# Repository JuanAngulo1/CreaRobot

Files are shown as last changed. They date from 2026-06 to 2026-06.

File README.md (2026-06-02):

# Sesame Robot — Build Guide (Custom Variant)

> Basado en el proyecto original [dorianborian/sesame-robot](https://github.com/dorianborian/sesame-robot) con modificaciones propias: alimentación por batería LiPo 2S con regulador LM2596, PCB personalizada y soporte para pantalla OLED con JST.

---

## Tabla de contenido

1. [Visión general](#1-visión-general)
2. [BOM — Lista de materiales](#2-bom--lista-de-materiales)
3. [Impresión 3D](#3-impresión-3d)
4. [Fase 1 — Electrónica: soldadura de la PCB](#4-fase-1--electrónica-soldadura-de-la-pcb)
5. [Fase 2 — Sistema de alimentación](#5-fase-2--sistema-de-alimentación)
6. [Fase 3 — Ensamblaje mecánico](#6-fase-3--ensamblaje-mecánico)
7. [Fase 4 — Montaje de la electrónica en el cuerpo](#7-fase-4--montaje-de-la-electrónica-en-el-cuerpo)
8. [Fase 5 — Calibración de servos](#8-fase-5--calibración-de-servos)
9. [Fase 6 — Firmware](#9-fase-6--firmware)

---

## 1. Visión general

El robot es un cuadrúpedo miniatura con 8 servos (2 por pata), controlado por un ESP32-S2 Mini (Lolin). La variante descrita aquí usa:

- Batería LiPo 2S (2× celda 14500 en battery holder 2S) → regulador buck LM2596 → 5 V para toda la electrónica.
- PCB de distribución personalizada con conectores JST XH 2.54 mm.
- Pantalla OLED SSD1306 0.96″ conectada por JST de 4 pines.
- Switch de encendido integrado en el top cover.

---

## 2. BOM — Lista de materiales

### Electrónica

| Componente | Especificación | Cant. |
|---|---|---|
| Microcontrolador | Lolin ESP32-S2 Mini | 1 |
| Servos | Tower Pro MG90S (o equivalente micro servo) | 8 |
| Pantalla OLED | SSD1306 0.96″, I2C | 1 |
| Regulador buck | LM2596 (módulo ajustable) | 1 |
| Batería | LiPo 14500 3.7 V × 2 (en battery holder 2S) | 2 |
| Switch | Rocker switch, enclave, 2 pines | 1 |

### Conectores y pasivos (para la PCB)

| Componente | Especificación | Cant. |
|---|---|---|
| Regleta hembra 2.54 mm | Para montar el ESP32-S2 Mini | 2 (según pinout) |
| Regleta macho 2.54 mm | Para señal de cada servo (S/VCC/GND por canal) | 8 × 3 pines |
| JST XH 2.54 mm 2 pines | Entrada de 5 V desde el buck | 1 |
| JST XH 2.54 mm 4 pines | Pantalla OLED (VCC, GND, SDA, SCL) | 1 |
| Cable 30 AWG | Señal | c/n |
| Cable 22 AWG | Potencia (VCC/GND servos y alimentación) | c/n |

### Hardware mecánico

| Componente | Especificación | Cant. |
|---|---|---|
| Tornillos autoroscantes | M2 × 5 mm | 10 |
| Tornillos métricos | M3 × 5 mm | 4 (regulador en techo) |
| Tuercas M3 | Para el regulador | 4 |

### Partes impresas en 3D

| Pieza | Cantidad |
|---|---|
| Marco interno (Internal Frame) | 1 |
| Top Cover | 1 |
| Bottom Cover | 1 |
| Joint L1, L2, L3, L4 | 1 c/u |
| Joint R1, R2, R3, R4 | 1 c/u |

---

## 3. Impresión 3D

Imprime todas las piezas antes de empezar el ensamblaje.

- **Material:** PLA (recomendado)
- **Relleno:** 30–40%
- **Capa:** 0.2 mm
- **Soportes:** Revisar el printing guide del repo original para orientaciones específicas del top cover

El set completo son **11 piezas impresas**: marco interno, top cover, bottom cover, y 8 joints (L1–L4, R1–R4).

![Componentes del robot]    
*Vista general de todos los componentes mecánicos e impresos*

---

## 4. Fase 1 — Electrónica: soldadura de la PCB

> Hazlo antes de tocar el ensamblaje mecánico. Con la PCB lista el cableado interno es mucho más limpio.

### 4.1 Montar el ESP32-S2 Mini

Solda dos **regletas hembra de 2.54 mm** en la PCB para que el ESP32-S2 Mini quede en zócalo (desmontable). El ESP32-S2 Mini requiere un reset manual para flashear (no tiene DTR/RTS automático), así que dejarlo desmontable facilita la vida.

### 4.2 Regletas para servos

Por cada uno de los 8 servos, solda una **regleta macho de 3 pines** (Señal / VCC / GND). Etiquétalas del 0 al 7 según el mapa de pines del firmware. Los servos L1–L4 y R1–R4 conectan aquí.

### 4.3 Conector de alimentación (entrada 5 V)

Solda un **JST XH 2.54 mm de 2 pines** para recibir los 5 V desde la salida del regulador LM2596. Esta es la única fuente de alimentación de toda la PCB (ESP32 + servos).

### 4.4 Conector de pantalla OLED

Solda un **JST XH 2.54 mm de 4 pines** con el siguiente orden:

```
Pin 1 → VCC (3.3 V o 5 V según la pantalla)
Pin 2 → GND
Pin 3 → SDA  (GPIO 33 en el S2 Mini por defecto)
Pin 4 → SCL  (GPIO 35 en el S2 Mini por defecto)
```

> Verificar el pinout exacto en el archivo de firmware antes de soldar.

### 4.5 Checklist de PCB

- [ ] ESP32-S2 Mini en zócalo, sin cortocircuitos visibles
- [ ] 8 regletas de servo soldadas y etiquetadas (0–7)
- [ ] JST 2 pines de alimentación
- [ ] JST 4 pines de OLED con orden VCC/GND/SDA/SCL correcto

---

## 5. Fase 2 — Sistema de alimentación

### 5.1 Batería

Usa **2 celdas 14500** (3.7 V cada una) en un **battery holder 2S**. Con ambas en serie obtienes ~7.4 V nominal (8.4 V cargadas). El holder va en la cavidad del Bottom Cover.

### 5.2 Regulador LM2596

El LM2596 convierte los 7.4–8.4 V de la batería a **5 V estables** para todo el sistema.

**Procedimiento de ajuste (trimear) antes de instalar:**

1. Conecta la batería (sin carga) al input del LM2596.
2. Con un multímetro en la salida, ajusta el **potenciómetro** del módulo hasta leer exactamente **5.0 V**.
3. Verifica con una carga leve (ej. una resistencia de 10 Ω) que la tensión se mantiene estable.

**Instalación:** El regulador se monta en el interior del top cover, pegado al techo, sujeto con **4 tornillos M3 × 5 mm** + tuercas. Deja espacio para que el potenciómetro quede accesible si necesitas reajustar.

### 5.3 Switch de encendido

El rocker switch se integra en el top cover. Se corta el positivo de la batería y se interrumpe con el switch — cuando está en OFF desconecta completamente el pack.

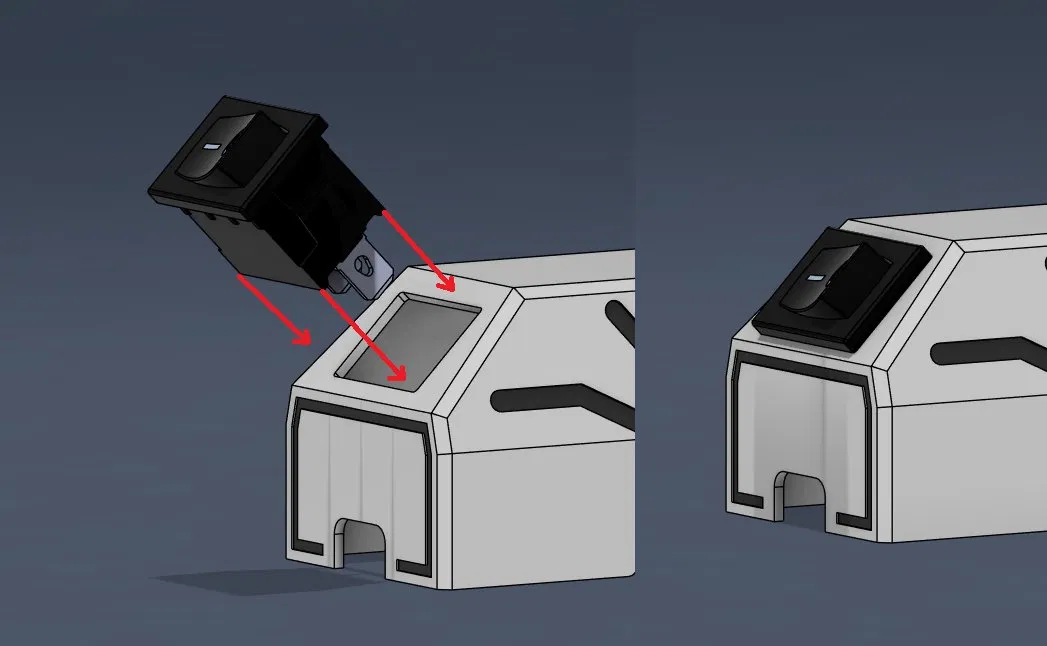
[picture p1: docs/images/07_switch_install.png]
Montaje del switch

*El switch encaja en la ranura del top cover presionando desde arriba*

---

## 6. Fase 3 — Ensamblaje mecánico

### 6.1 Montaje de servos en joints L3, L4, R3, R4 (patas traseras/delanteras, motor lateral)

Cada joint lateral (L3/R3 = muslo, L4/R4 = tibia) recibe un servo con el **engranaje apuntando hacia arriba** desde la perspectiva de la pata.

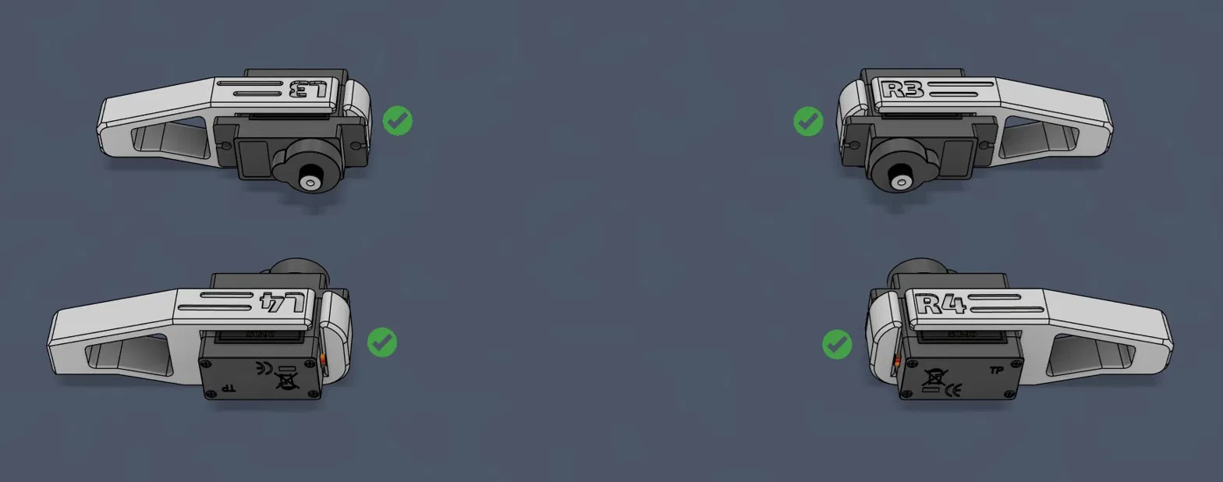
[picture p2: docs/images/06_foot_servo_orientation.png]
Orientación correcta L3/R3 y L4/R4

*Check verde = orientación correcta del servo en cada joint*

Fijación: **2× M2 × 5 mm autoroscantes** por servo (los orificios de montaje del servo encajan en el slot del joint).

### 6.2 Montaje de servos en joints L1, L2, R1, R2 (cadera)

Los joints de cadera son la articulación entre el cuerpo y la pata. Se montan en pares (L1+L2 lado izquierdo, R1+R2 lado derecho).

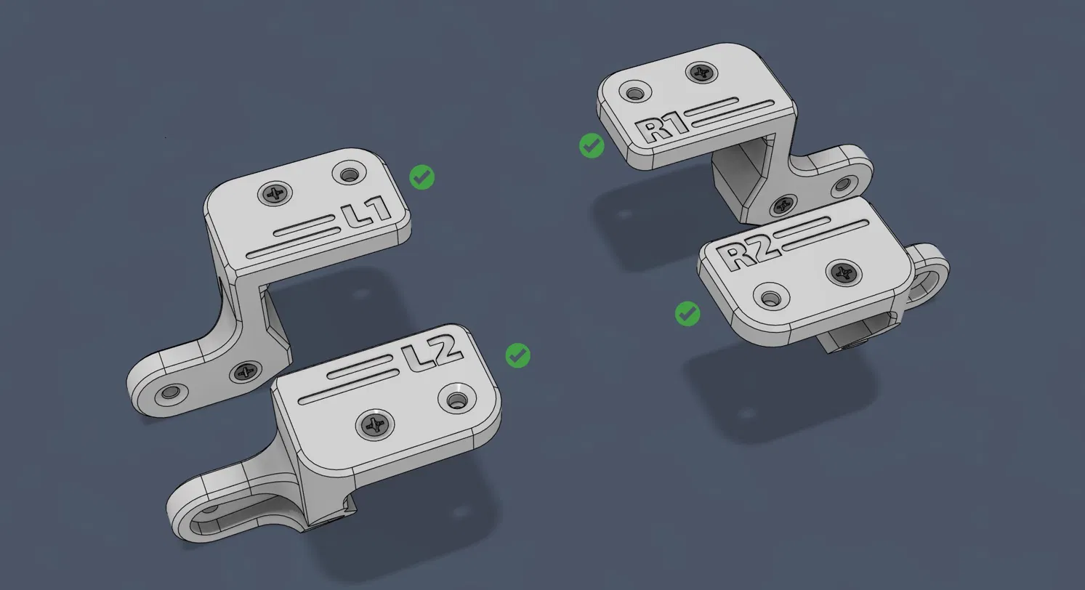
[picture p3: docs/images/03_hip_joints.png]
Joints de cadera L1/L2 y R1/R2

*Los cuatro joints de cadera, verificados con check verde*

> ⚠️ En este punto **NO montes todavía los servos** en los joints de cadera. Primero van los joints al frame, después los servos. Ver imagen de referencia:

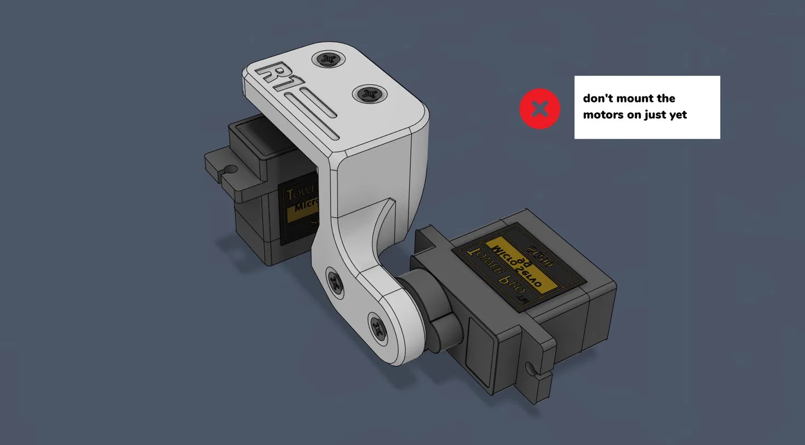
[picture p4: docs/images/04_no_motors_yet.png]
No montar servos todavía


### 6.3 Montaje en el marco interno

Los servos de cadera (motores 1–4, que corresponden a L1/L2/R1/R2) se insertan en el internal frame desde abajo. El servo desliza hacia arriba dentro de su slot, con las pestañas del servo encajando en las guías del frame.

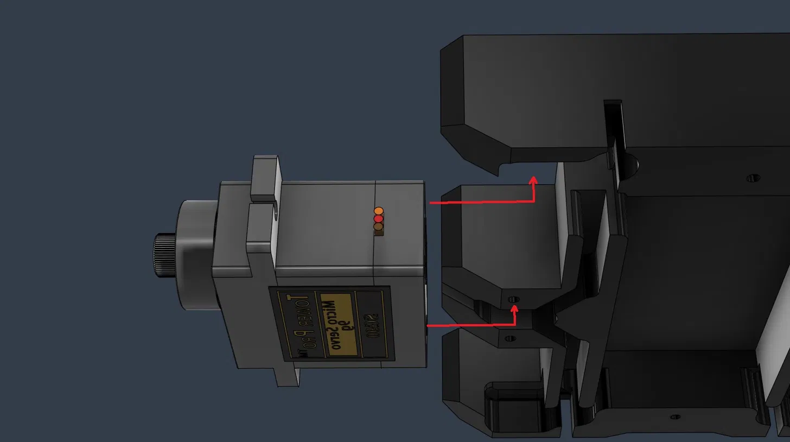
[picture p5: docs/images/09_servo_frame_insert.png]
Inserción del servo en el frame


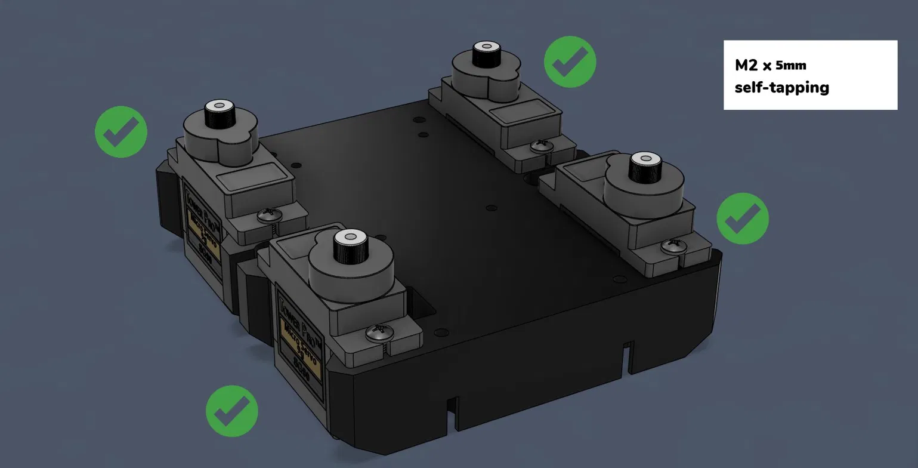
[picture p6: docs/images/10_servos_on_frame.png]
Los 4 servos montados en el frame

*4 servos fijados al frame con M2 × 5 mm self-tapping, check verde en cada esquina*

### 6.4 Verificación de orientación antes de continuar

Con los joints y el frame armados, revisa que la geometría de patas corresponda al diagrama de ángulos. **Todos los servos deben estar a 90° para el ensamblaje inicial** (posición neutra):

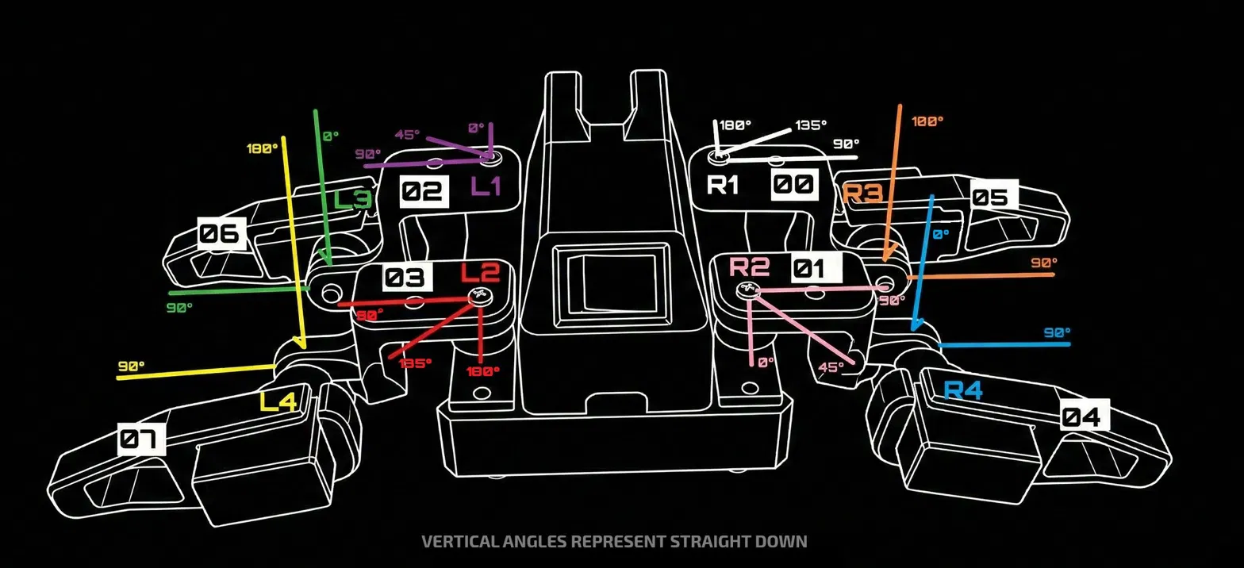
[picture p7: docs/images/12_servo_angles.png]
Diagrama de ángulos

*Mapa de ángulos objetivo por servo. "Vertical angles represent straight down"*

---

## 7. Fase 4 — Montaje de la electrónica en el cuerpo

### 7.1 PCB en el internal frame

La PCB de distribución va en el internal frame. Alinea los orificios de montaje y fija con tornillos M2.

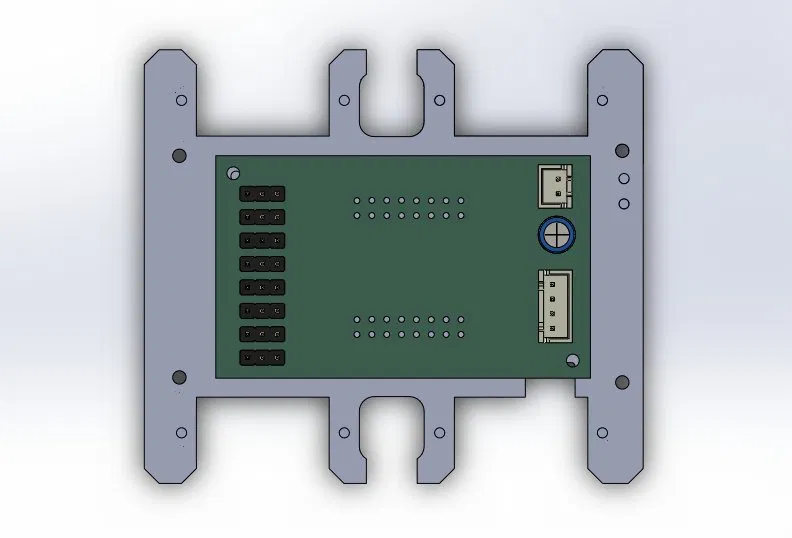
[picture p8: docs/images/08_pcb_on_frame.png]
PCB en el frame


### 7.2 Regulador en el top cover

El LM2596 va en el interior del top cover, pegado al techo. Sujétalo con los **4 M3 × 5 mm** mencionados en la Fase 2.

### 7.3 Pantalla OLED

La pantalla tiene un soporte impreso que la fija en la ranura frontal del top cover. Conecta el cable JST de 4 pines que va de la pantalla a la PCB.

### 7.4 Batería en el bottom cover

El battery holder 2S va en la cavidad del bottom cover. El cable positivo pasa por el switch antes de llegar al input del LM2596.

---

## 8. Fase 5 — Calibración de servos

Antes de poner los brazos de servo (servo horns) en su posición definitiva, todos los servos deben estar en **90°**.

1. Flashea `sesame-motor-tester.ino` (debugging firmware) al ESP32-S2 Mini via Arduino IDE.
2. Abre el Serial Monitor a 115200 baud.
3. Sigue el menú para mover cada servo individualmente a 90°.
4. Anota el offset de cada canal si el servo no queda perfectamente centrado.
5. Fija el servo horn con los servos ya en 90° antes de cerrar las articulaciones.

> Los offsets se ajustan en los parámetros de configuración del firmware principal.

---

## 9. Fase 6 — Firmware

### 9.1 Requisitos

- Arduino IDE con soporte para ESP32 (board manager: `https://raw.githubusercontent.com/espressif/arduino-esp32/gh-pages/package_esp32_index.json`)
- Board seleccionada: **LOLIN S2 Mini**

### 9.2 Flash del firmware principal

```bash
# Clonar el repo
git clone https://github.com/dorianborian/sesame-robot.git
cd sesame-robot/firmware
```

Abre `sesame-firmware-main.ino` en Arduino IDE y carga al ESP32-S2 Mini.

> ⚠️ El S2 Mini **no tiene DTR/RTS automático**. Para entrar en modo bootloader: mantén presionado **BOOT**, presiona y suelta **RST**, luego suelta **BOOT**. Después de flashear, presiona RST una vez para arrancar.

### 9.3 Control

Una vez encendido, el ESP32 levanta un **Access Point WiFi**. Conéctate desde tu teléfono a la red del robot y accede a la IP del AP (normalmente `192.168.4.1`) para ver el control web.

## Checklist final de ensamblaje

- [ ] PCB soldada y revisada sin cortocircuitos
- [ ] Regulador LM2596 trimeado a 5.0 V
- [ ] Switch probado (corta el positivo correctamente)
- [ ] Todos los servos centrados a 90° con `sesame-motor-tester`
- [ ] Joints y servos orientados según el diagrama de ángulos
- [ ] OLED conectada y mostrando algo al encender
- [ ] Firmware principal cargado, WiFi AP activo
- [ ] Batería colocada en el bottom cover, robot cierra correctamente

---

*Basado en [dorianborian/sesame-robot](https://github.com/dorianborian/sesame-robot). Variante con LiPo 2S + LM2596 + PCB de distribución personalizada.*

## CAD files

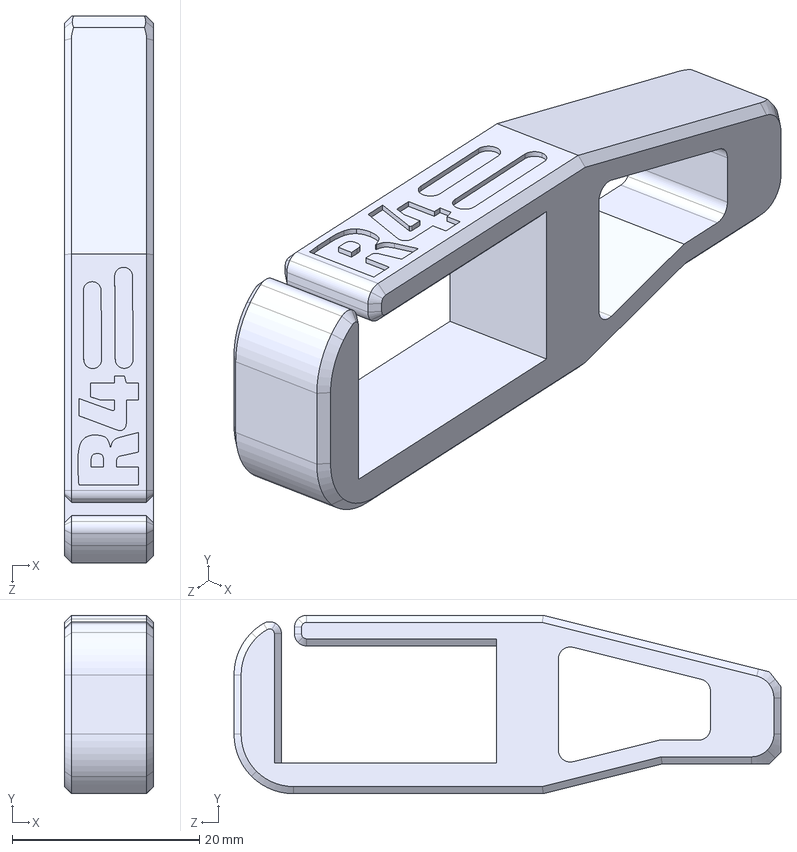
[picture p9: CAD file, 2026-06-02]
hardware/cad-printing/foot-joint-R4.step.STEP
9.53 x 19.1 x 58.4 mm

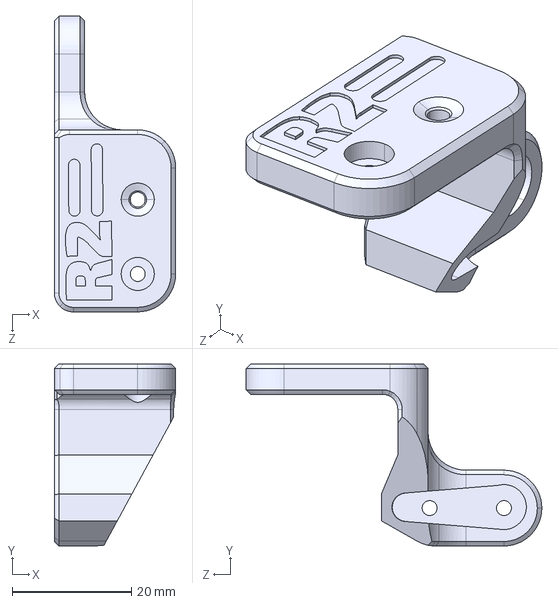
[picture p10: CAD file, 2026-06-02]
hardware/cad-printing/femurjoint-R2.STEP
20.3 x 30.5 x 49.5 mm

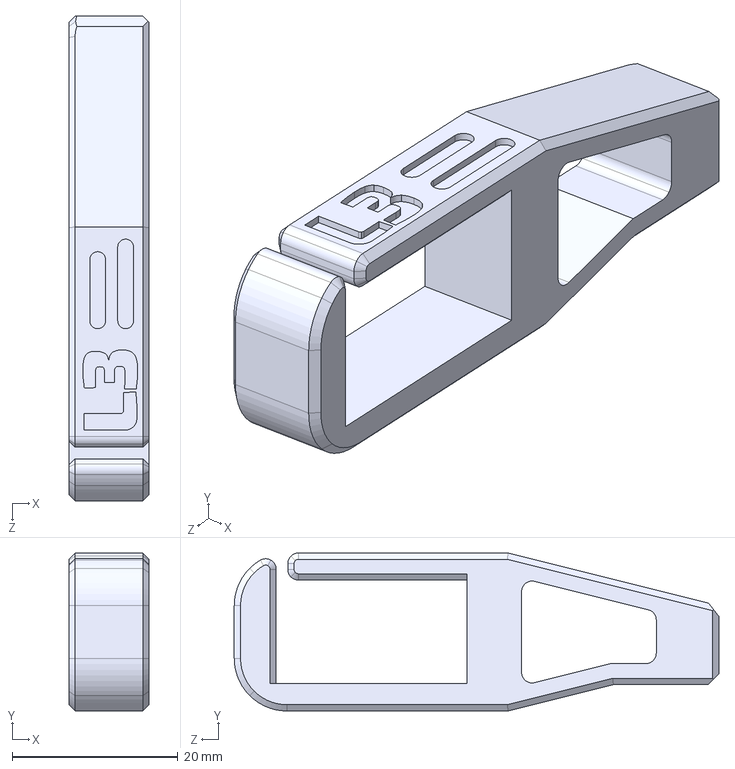
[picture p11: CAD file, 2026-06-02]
hardware/cad-printing/foot-joint-L3.step.STEP
9.70 x 19.1 x 58.4 mm

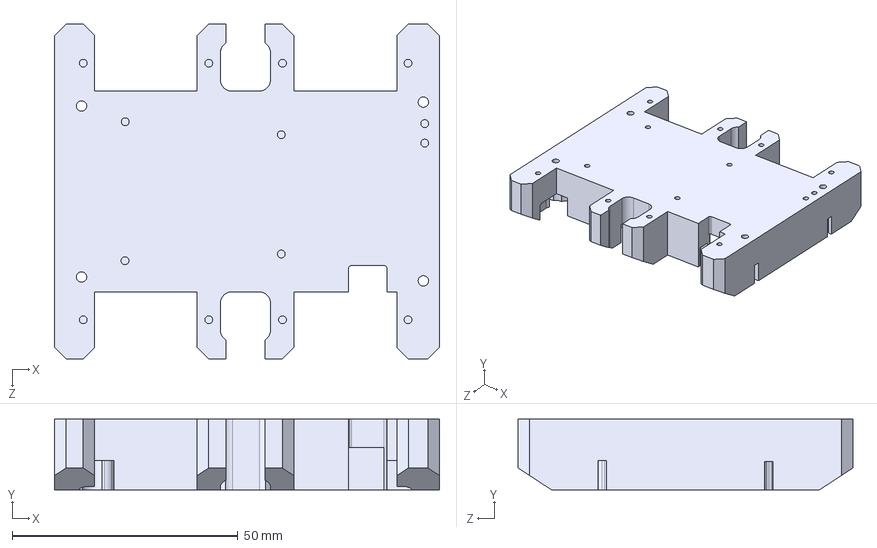
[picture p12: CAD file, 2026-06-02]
hardware/cad-printing/Internal-Frame.STEP
85.2 x 15.7 x 74.1 mm

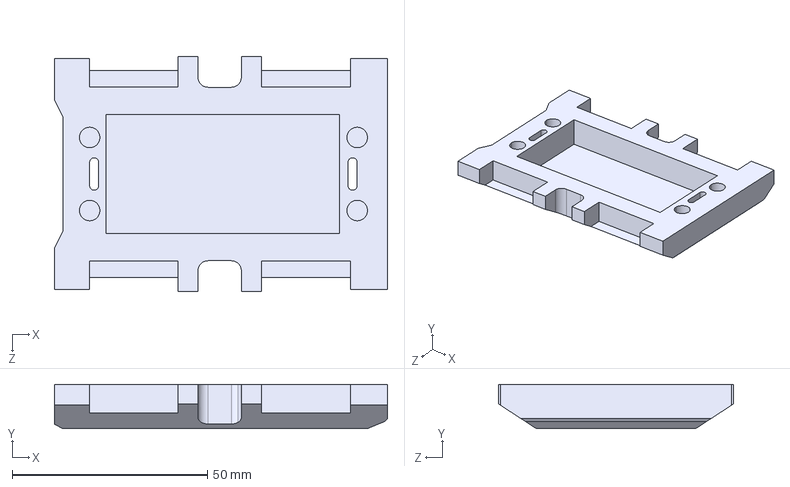
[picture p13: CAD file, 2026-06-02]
hardware/cad-printing/Bottom-Cover.STEP
85.2 x 11.3 x 60.2 mm

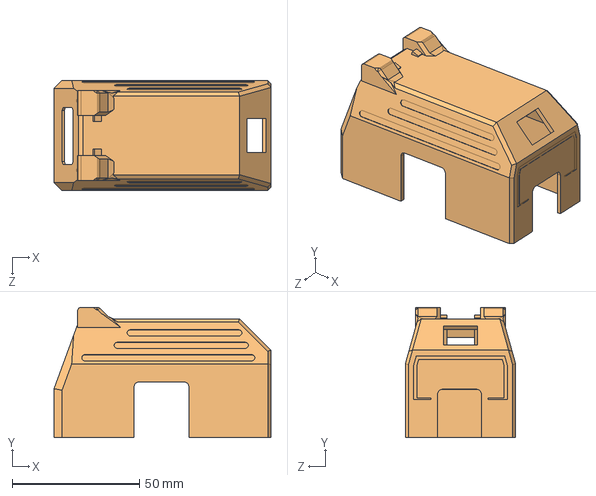
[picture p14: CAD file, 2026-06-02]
hardware/cad-printing/eBom-FreeParts.STEP
85.2 x 51.2 x 43.4 mm

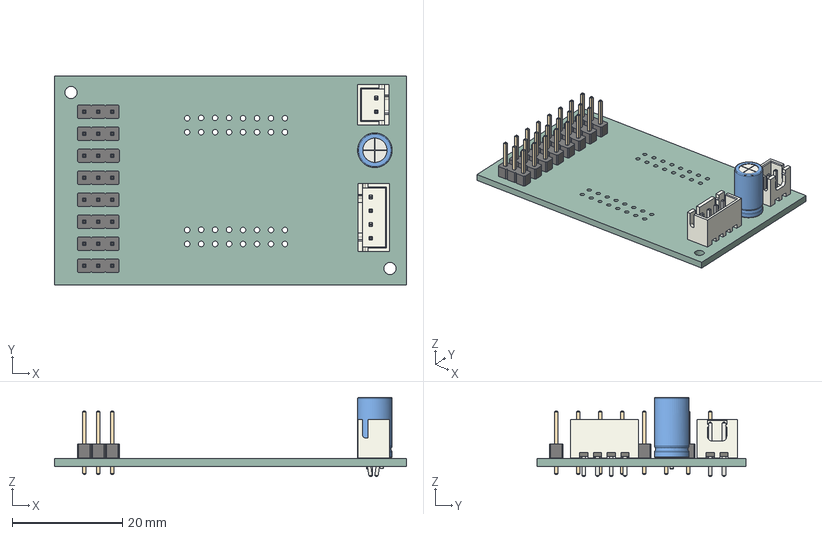
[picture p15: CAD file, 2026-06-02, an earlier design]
hardware/pcb_v2/PCB_sesame/PCB_sesame.step
64.0 x 38.0 x 14.4 mm
PinHeader_1x03_P2.54mm_Vertical x 8
JST_XH_B4B-XH-A_1x04_P2.50mm_Vertical
C_Radial_D6.3mm_H11.0mm_P2.50mm
JST_XH_B2B-XH-A_1x02_P2.50mm_Vertical
PCB_sesame_PCB

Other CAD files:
hardware/cad-printing/foot-joint-L4.step.STEP
hardware/cad-printing/femur-joint-L1.STEP
hardware/cad-printing/femur-joint-R1.STEP
hardware/cad-printing/foot-joint-R3.step.STEP
hardware/cad-printing/femur-joint-L2.STEP

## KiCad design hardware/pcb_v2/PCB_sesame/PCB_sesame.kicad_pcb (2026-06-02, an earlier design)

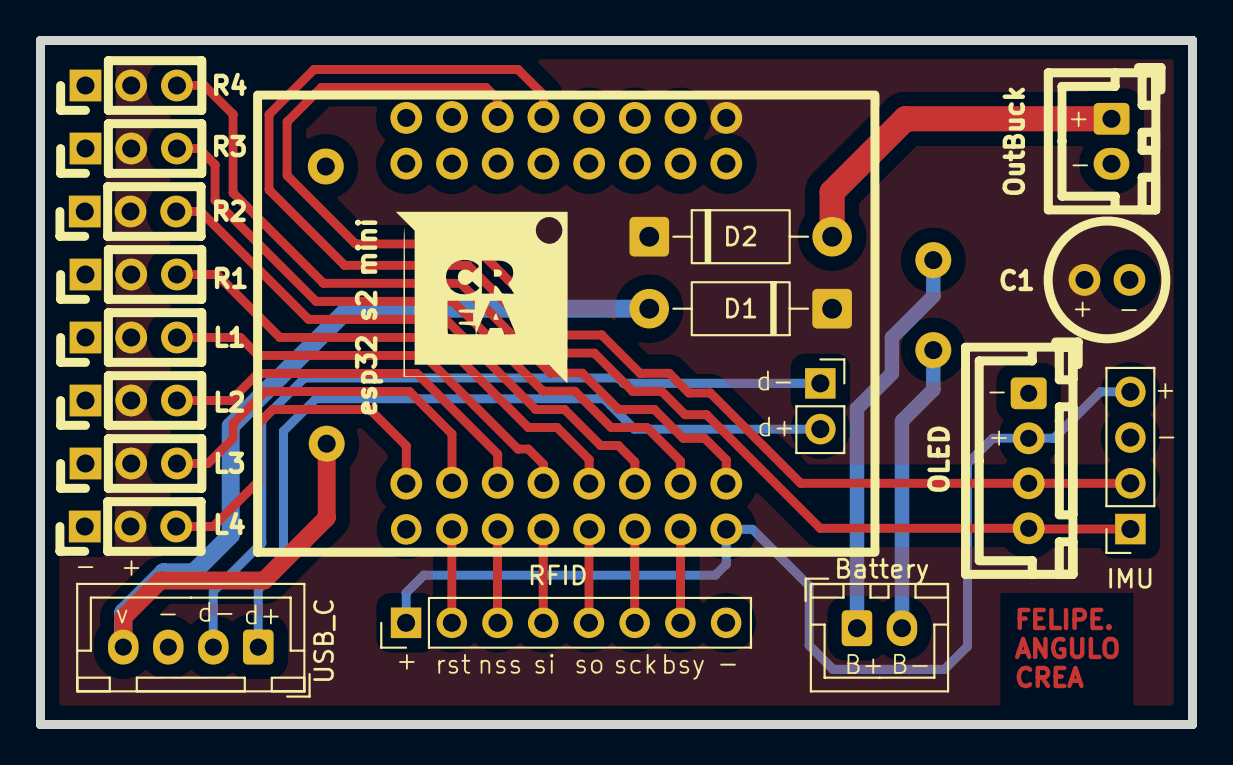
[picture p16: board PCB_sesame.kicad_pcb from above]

Board: 2 copper layers, 64.0 x 38.0 mm, 21 parts (0 on the bottom side), 25 nets.

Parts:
.: LOGO; crea_logo
Battery: Conn_01x02_Socket; JST_XH_B2B-XH-A_1x02_P2.50mm_Vertical
C1: 100uF; C_Radial_D6.3mm_H11.0mm_P2.50mm
D1, D2: 1N5819; D_DO-41_SOD81_P10.16mm_Horizontal
IMU: Conn_01x04_Pin; PinSocket_1x04_P2.54mm_Vertical
J13: Conn_01x02_Socket; PinSocket_1x02_P2.54mm_Vertical
L1, L2, L3, L4: Conn_01x03_Pin; PinHeader_1x03_P2.54mm_Vertical
OLED: Conn_01x04_Pin; JST_XH_B4B-XH-A_1x04_P2.50mm_Vertical
OutBuck: Conn_01x02_Pin; JST_XH_B2B-XH-A_1x02_P2.50mm_Vertical
R1, R2, R3, R4: Conn_01x03_Pin; PinHeader_1x03_P2.54mm_Vertical
RFID: Conn_01x08_Pin; PinHeader_1x08_P2.54mm_Vertical
U2: modulo_Carga
USB_C: Conn_01x04_Socket; JST_XH_B4B-XH-A_1x04_P2.50mm_Vertical
esp32 s2 mini: ESP32 MINI; ESP32 S2 MINI

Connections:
3.3V: IMU.4, OLED.2, RFID.1, esp32 s2 mini.8 (3.3V)
5V: C1.1, D1.1 (K), D2.1 (K), L1.2, L2.2, L3.2, L4.2, R1.2, R2.2, R3.2, R4.2, esp32 s2 mini.32 (Vbus)
BUSY: RFID.7, esp32 s2 mini.7 (GPIO12)
D+: J13.2, USB_C.1
D-: J13.1, USB_C.2
GND: C1.2, IMU.3, L1.1, L2.1, L3.1, L4.1, OLED.1, OutBuck.2, R1.1, R2.1, R3.1, R4.1, RFID.8, U2.2 (GND), USB_C.3, esp32 s2 mini.23 (GND), esp32 s2 mini.31 (GND)
GPIO1: L4.3, esp32 s2 mini.9 (GPIO1)
GPIO2: L3.3, esp32 s2 mini.10 (GPIO2)
GPIO4: L2.3, esp32 s2 mini.11 (GPIO4)
GPIO6: L1.3, esp32 s2 mini.12 (GPIO6)
GPIO8: R1.3, esp32 s2 mini.13 (GPIO8)
GPIO10: R2.3, esp32 s2 mini.14 (GPIO10)
GPIO13: R3.3, esp32 s2 mini.15 (GPIO13)
GPIO14: R4.3, esp32 s2 mini.16 (GPIO14)
GPIO33: IMU.1, OLED.4, esp32 s2 mini.28 (GPIO33)
GPIO35: IMU.2, OLED.3, esp32 s2 mini.27 (GPIO35)
MISO: RFID.5, esp32 s2 mini.5 (GPIO9)
MOSI: RFID.4, esp32 s2 mini.4 (GPIO7)
NSS: RFID.3, esp32 s2 mini.3 (GPIO5)
unnamed: Battery.1, U2.4 (B+)
unnamed: Battery.2, U2.3 (B-)
unnamed: D2.2 (A), OutBuck.1
RST: RFID.2, esp32 s2 mini.2 (GPIO3)
SCK: RFID.6, esp32 s2 mini.6 (GPIO11)
VBUS: D1.2 (A), U2.1 (VBUS), USB_C.4

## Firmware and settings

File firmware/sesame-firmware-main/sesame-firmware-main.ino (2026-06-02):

#include <WiFi.h>
#include <WebServer.h>
#include <DNSServer.h>
#include <ESPmDNS.h>
#include <Wire.h>
#include <ESP32Servo.h>
#include <Adafruit_GFX.h>
#include <Adafruit_SSD1306.h>
#include "face-bitmaps.h"
#include "movement-sequences.h"
#include "captive-portal.h"

#if defined(__has_include)
  #if __has_include(<esp_heap_caps.h>)
    #include <esp_heap_caps.h>
    #define HAS_EXTMEM_HEAP_CONTROL 1
  #else
    #define HAS_EXTMEM_HEAP_CONTROL 0
  #endif
#else
  #define HAS_EXTMEM_HEAP_CONTROL 0
#endif

// --- Access Point Configuration ---
// This is the network the Robot will create
#define AP_SSID  "Sesame-Controller"
#define AP_PASS  "12345678" // Must be at least 8 characters

// --- Station Mode Configuration (Optional) ---
// Set these to connect to your home/office WiFi network
// Leave NETWORK_SSID empty to disable station mode
#define NETWORK_SSID ""  // Your WiFi network name
#define NETWORK_PASS ""  // Your WiFi password
#define ENABLE_NETWORK_MODE false  // Set to true to enable network connection attempts

// --- PSRAM Configuration ---
// Hard-disabled by default to avoid PSRAM-related instability.
#define FORCE_DISABLE_PSRAM_HEAP true

#define SCREEN_WIDTH 128
#define SCREEN_HEIGHT 64
#define OLED_RESET -1
#define OLED_I2C_ADDR 0x3C

// I2C Pins for Distro Board V2
//#define I2C_SDA 8
//#define I2C_SCL 9

// I2C Pins for Distro Board
//#define I2C_SDA 21
//#define I2C_SCL 22

// I2C Pins for S2 Mini Board
#define I2C_SDA 33
#define I2C_SCL 35


// DNS Server for Captive Portal
DNSServer dnsServer;
const byte DNS_PORT = 53;

Adafruit_SSD1306 display(SCREEN_WIDTH, SCREEN_HEIGHT, &Wire, OLED_RESET);
WebServer server(80);

// Global state for animations
String currentCommand = "";
String currentFaceName = "default";
const unsigned char* const* currentFaceFrames = nullptr;
uint8_t currentFaceFrameCount = 0;
uint8_t currentFaceFrameIndex = 0;
unsigned long lastFaceFrameMs = 0;
int faceFps = 8;
FaceAnimMode currentFaceMode = FACE_ANIM_LOOP;
int8_t faceFrameDirection = 1;
bool faceAnimFinished = false;
int currentFaceFps = 0;
bool idleActive = false;
bool idleBlinkActive = false;
unsigned long nextIdleBlinkMs = 0;
uint8_t idleBlinkRepeatsLeft = 0;

// WiFi Info Scrolling
unsigned long lastInputTime = 0;
bool firstInputReceived = false;
bool showingWifiInfo = false;
int wifiScrollPos = 0;
unsigned long lastWifiScrollMs = 0;
String wifiInfoText = "";

// Network Mode
bool networkConnected = false;
IPAddress networkIP;
String deviceHostname = "sesame-robot";

// PSRAM Status
const bool psramForceDisabled = FORCE_DISABLE_PSRAM_HEAP;
bool psramDetected = false;
bool psramHeapEnabled = false;
size_t psramTotalBytes = 0;
size_t psramFreeBytes = 0;

// Servo Pins for Distro Board
// ======================================================================
// Pin numbers are coorisponding to the ESP32 GPIO pins and may differ based on which board you use.
// If you are using a different board, please adjust the servoPins array accordingly.
// ======================================================================
Servo servos[8];
// Sesame Distro Board V2 Pinout
//const int servoPins[8] = {4, 5, 6, 7, 15, 16, 17, 18};

// Sesame Distro Board Pinout
//const int servoPins[8] = {15, 2, 23, 19, 4, 16, 17, 18};

// Lolin S2 Mini Pinout
const int servoPins[8] = {8,10,6,4, 14, 13, 2, 1};

// Subtrim values for each servo (offset in degrees)
int8_t servoSubtrim[8] = {2, 0, 0, 6, 4, -2, 12, 4};


// Animation constants
int frameDelay = 100;
int walkCycles = 10;
int motorCurrentDelay = 20; // ms delay between motor movements to prevent over-current

struct FaceEntry {
  const char* name;
  const unsigned char* const* frames;
  uint8_t maxFrames;
};

static const uint8_t MAX_FACE_FRAMES = 6;

#define MAKE_FACE_FRAMES(name) \
  const unsigned char* const face_##name##_frames[] = { \
    epd_bitmap_##name, epd_bitmap_##name##_1, epd_bitmap_##name##_2, \
    epd_bitmap_##name##_3, epd_bitmap_##name##_4, epd_bitmap_##name##_5 \
  };

#define X(name) MAKE_FACE_FRAMES(name)
FACE_LIST
#undef X
#undef MAKE_FACE_FRAMES

const FaceEntry faceEntries[] = {
#define X(name) { #name, face_##name##_frames, MAX_FACE_FRAMES },
  FACE_LIST
#undef X
  { "default", face_defualt_frames, MAX_FACE_FRAMES }
};

struct FaceFpsEntry {
  const char* name;
  uint8_t fps;
};

const FaceFpsEntry faceFpsEntries[] = {
  { "walk", 1 },
  { "rest", 1 },
  { "swim", 1 },
  { "dance", 1 },
  { "wave", 1 },
  { "point", 5 },
  { "stand", 1 },
  { "cute", 1 },
  { "pushup", 1 },
  { "freaky", 1 },
  { "bow", 1 },
  { "worm", 1 },
  { "shake", 1 },
  { "shrug", 1 },
  { "dead", 2 },
  { "crab", 1 },
  { "idle", 1 },
  { "idle_blink", 7 },
  { "default", 1 },
  // Conversational faces (manually controlled by Python - no auto-animation)
  { "happy", 1 },
  { "talk_happy", 1 },
  { "sad", 1 },
  { "talk_sad", 1 },
  { "angry", 1 },
  { "talk_angry", 1 },
  { "surprised", 1 },
  { "talk_surprised", 1 },
  { "sleepy", 1 },
  { "talk_sleepy", 1 },
  { "love", 1 },
  { "talk_love", 1 },
  { "excited", 1 },
  { "talk_excited", 1 },
  { "confused", 1 },
  { "talk_confused", 1 },
  { "thinking", 1 },
  { "talk_thinking", 1 },
};


// Prototypes
void setServoAngle(uint8_t channel, int angle);
void updateFaceBitmap(const unsigned char* bitmap);
void setFace(const String& faceName);
void setFaceMode(FaceAnimMode mode);
void setFaceWithMode(const String& faceName, FaceAnimMode mode);
void updateAnimatedFace();
void delayWithFace(unsigned long ms);
void enterIdle();
void exitIdle();
void updateIdleBlink();
int getFaceFpsForName(const String& faceName);
bool pressingCheck(String cmd, int ms);
void handleGetSettings();
void handleSetSettings();
void handleGetStatus();
void handleApiCommand();
void updateWifiInfoScroll();
void recordInput();
void refreshPsramStatus();
void configurePsram();

void refreshPsramStatus() {
  psramDetected = psramFound();
  if (psramDetected) {
    psramTotalBytes = ESP.getPsramSize();
    psramFreeBytes = ESP.getFreePsram();
  } else {
    psramTotalBytes = 0;
    psramFreeBytes = 0;
  }
}

void configurePsram() {
  refreshPsramStatus();
  if (!psramDetected) {
    psramHeapEnabled = false;
    Serial.println("PSRAM not detected.");
    return;
  }

#if HAS_EXTMEM_HEAP_CONTROL
  if (FORCE_DISABLE_PSRAM_HEAP) {
    // Use an unreachable threshold so regular heap allocations stay internal.
    heap_caps_malloc_extmem_enable((size_t)-1);
    psramHeapEnabled = false;
    Serial.println("PSRAM detected and forcibly disabled for heap allocations.");
  } else {
    // Allow heap allocations to use PSRAM.
    heap_caps_malloc_extmem_enable(0);
    psramHeapEnabled = true;
    Serial.println("PSRAM detected and heap allocations are enabled.");
  }
#else
  psramHeapEnabled = !FORCE_DISABLE_PSRAM_HEAP;
  if (FORCE_DISABLE_PSRAM_HEAP) {
    Serial.println("PSRAM detected, but heap control API is unavailable in this build.");
    Serial.println("FATAL: refusing to boot with PSRAM enabled. Update board core/toolchain.");
    while (true) {
      delay(1000);
    }
  } else {
    Serial.println("PSRAM detected.");
  }
#endif

  refreshPsramStatus();
  Serial.print("PSRAM total bytes: ");
  Serial.println((unsigned long)psramTotalBytes);
  Serial.print("PSRAM free bytes: ");
  Serial.println((unsigned long)psramFreeBytes);
}

void handleRoot() {
  server.send(200, "text/html", index_html);
}

void handleCommandWeb() {
  // We send 200 OK immediately so the web browser doesn't hang waiting for animation to finish
  if (server.hasArg("pose")) {
    currentCommand = server.arg("pose");
    recordInput();
    exitIdle();
    server.send(200, "text/plain", "OK"); 
  } 
  else if (server.hasArg("go")) {
    currentCommand = server.arg("go");
    recordInput();
    exitIdle();
    server.send(200, "text/plain", "OK");
  } 
  else if (server.hasArg("stop")) {
    currentCommand = "";
    recordInput();
    server.send(200, "text/plain", "OK");
  }
  else if (server.hasArg("motor") && server.hasArg("value")) {
    int motorNum = server.arg("motor").toInt();
    int servoIdx = servoNameToIndex(server.arg("motor"));
    int angle = server.arg("value").toInt();
    if (motorNum >= 1 && motorNum <= 8 && angle >= 0 && angle <= 180) {
      setServoAngle(motorNum - 1, angle); // Convert 1-based to 0-based index
      recordInput();
      server.send(200, "text/plain", "OK");
    } else if (servoIdx != -1 && angle >= 0 && angle <= 180) {
      setServoAngle(servoIdx, angle);
      recordInput();
      server.send(200, "text/plain", "OK");
    } else {
      server.send(400, "text/plain", "Invalid motor or angle");
    }
  }
  else {
    server.send(400, "text/plain", "Bad Args");
  }
}

void handleGetSettings() {
  String json = "{";
  json += "\"frameDelay\":" + String(frameDelay) + ",";
  json += "\"walkCycles\":" + String(walkCycles) + ",";
  json += "\"motorCurrentDelay\":" + String(motorCurrentDelay) + ",";
  json += "\"faceFps\":" + String(faceFps);
  json += "}";
  server.send(200, "application/json", json);
}

void handleSetSettings() {
  if (server.hasArg("frameDelay")) frameDelay = server.arg("frameDelay").toInt();
  if (server.hasArg("walkCycles")) walkCycles = server.arg("walkCycles").toInt();
  if (server.hasArg("motorCurrentDelay")) motorCurrentDelay = server.arg("motorCurrentDelay").toInt();
  if (server.hasArg("faceFps")) faceFps = (int)max(1L, server.arg("faceFps").toInt());
  server.send(200, "text/plain", "OK");
}

// API endpoint for network clients to get robot status
void handleGetStatus() {
  refreshPsramStatus();

  String json = "{";
  json += "\"currentCommand\":\"" + currentCommand + "\",";
  json += "\"currentFace\":\"" + currentFaceName + "\",";
  json += "\"networkConnected\":" + String(networkConnected ? "true" : "false") + ",";
  json += "\"psramForceDisabled\":" + String(psramForceDisabled ? "true" : "false") + ",";
  json += "\"psramDetected\":" + String(psramDetected ? "true" : "false") + ",";
  json += "\"psramHeapEnabled\":" + String(psramHeapEnabled ? "true" : "false") + ",";
  json += "\"psramTotalBytes\":" + String((unsigned long)psramTotalBytes) + ",";
  json += "\"psramFreeBytes\":" + String((unsigned long)psramFreeBytes) + ",";
  json += "\"apIP\":\"" + WiFi.softAPIP().toString() + "\"";
  if (networkConnected) {
    json += ",\"networkIP\":\"" + networkIP.toString() + "\"";
  }
  json += "}";
  server.send(200, "application/json", json);
}

// API endpoint for network clients to send commands (JSON-based)
void handleApiCommand() {
  if (server.method() != HTTP_POST) {
    server.send(405, "application/json", "{\"error\":\"Method not allowed\"}");
    return;
  }
  
  String body = server.arg("plain");
  
  Serial.println("API Command received:");
  Serial.println(body);
  
  // Check for face-only command (no movement)
  int faceOnlyStart = body.indexOf("\"face\":\"");
  if (faceOnlyStart == -1) {
    faceOnlyStart = body.indexOf("\"face\": \"");
  }
  
  // If we have a face but no command field, it's face-only
  bool faceOnly = (faceOnlyStart > 0 && body.indexOf("\"command\":") == -1 && body.indexOf("\"command\": ") == -1);
  
  String command = "";
  String face = "";
  
  // Parse face
  if (faceOnlyStart > 0) {
    faceOnlyStart = body.indexOf("\"", faceOnlyStart + 6) + 1;
    int faceEnd = body.indexOf("\"", faceOnlyStart);
    if (faceEnd > faceOnlyStart) {
      face = body.substring(faceOnlyStart, faceEnd);
      Serial.print("Parsed face: ");
      Serial.println(face);
    }
  }
  
  // Parse command (if not face-only)
  if (!faceOnly) {
    int cmdStart = body.indexOf("\"command\":\"");
    if (cmdStart == -1) {
      cmdStart = body.indexOf("\"command\": \"");
    }
    
    if (cmdStart == -1) {
      Serial.println("Error: command field not found");
      server.send(400, "application/json", "{\"error\":\"Missing command field\"}");
      return;
    }
    
    cmdStart = body.indexOf("\"", cmdStart + 10) + 1;
    int cmdEnd = body.indexOf("\"", cmdStart);
    
    if (cmdEnd <= cmdStart) {
      Serial.println("Error: invalid command format");
      server.send(400, "application/json", "{\"error\":\"Invalid command format\"}");
      return;
    }
    
    command = body.substring(cmdStart, cmdEnd);
    Serial.print("Parsed command: ");
    Serial.println(command);
  }
  
  // Set face if provided
  if (face.length() > 0) {
    setFace(face);
  }
  
  // If face-only, just acknowledge
  if (faceOnly) {
    recordInput();
    server.send(200, "application/json", "{\"status\":\"ok\",\"message\":\"Face updated\"}");
    return;
  }
  
  // Execute command
  if (command == "stop") {
    currentCommand = "";
    recordInput();
    server.send(200, "application/json", "{\"status\":\"ok\",\"message\":\"Command stopped\"}");
  } else {
    currentCommand = command;
    recordInput();
    exitIdle();
    server.send(200, "application/json", "{\"status\":\"ok\",\"message\":\"Command executed\"}");
  }
}
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
void loop() {
  // Process DNS requests for captive portal
  dnsServer.processNextRequest();
  
  server.handleClient();
  updateAnimatedFace();
  updateIdleBlink();
  updateWifiInfoScroll();

  if (currentCommand != "") {
    String cmd = currentCommand;
    if (cmd == "forward") runWalkPose();
    else if (cmd == "backward") runWalkBackward();
    else if (cmd == "left") runTurnLeft();
    else if (cmd == "right") runTurnRight();
    else if (cmd == "rest") { runRestPose(); if (currentCommand == "rest") currentCommand = ""; }
    else if (cmd == "stand") { runStandPose(1); if (currentCommand == "stand") currentCommand = ""; }
    else if (cmd == "wave") runWavePose();
    else if (cmd == "dance") runDancePose();
    else if (cmd == "swim") runSwimPose();
    else if (cmd == "point") runPointPose();
    else if (cmd == "pushup") runPushupPose();
    else if (cmd == "bow") runBowPose();
    else if (cmd == "cute") runCutePose();
    else if (cmd == "freaky") runFreakyPose();
    else if (cmd == "worm") runWormPose();
    else if (cmd == "shake") runShakePose();
    else if (cmd == "shrug") runShrugPose();
    else if (cmd == "dead") runDeadPose();
    else if (cmd == "crab") runCrabPose();
  }
  
  // Serial CLI for debugging (can be used to diagnose servo position issues and wiring)
  if (Serial.available()) {
    static char command_buffer[32];
    static byte buffer_pos = 0;
    char c = Serial.read();
    if (c == '\n' || c == '\r') {
      if (buffer_pos > 0) {
        command_buffer[buffer_pos] = '\0';
        int motorNum, angle;
        recordInput();
        if(strcmp(command_buffer, "run walk") == 0 || strcmp(command_buffer, "rn wf") == 0) { currentCommand = "forward"; runWalkPose(); currentCommand = ""; }
        else if(strcmp(command_buffer, "rn wb") == 0) { currentCommand = "backward"; runWalkBackward(); currentCommand = ""; }
        else if(strcmp(command_buffer, "rn tl") == 0) { currentCommand = "left"; runTurnLeft(); currentCommand = ""; }
        else if(strcmp(command_buffer, "rn tr") == 0) { currentCommand = "right"; runTurnRight(); currentCommand = ""; }
        else if(strcmp(command_buffer, "run rest") == 0 || strcmp(command_buffer, "rn rs") == 0) runRestPose();
        else if(strcmp(command_buffer, "run stand") == 0 || strcmp(command_buffer, "rn st") == 0) runStandPose(1);
        else if(strcmp(command_buffer, "rn wv") == 0) { currentCommand = "wave"; runWavePose(); }
        else if(strcmp(command_buffer, "rn dn") == 0) { currentCommand = "dance"; runDancePose(); }
        else if(strcmp(command_buffer, "rn sw") == 0) { currentCommand = "swim"; runSwimPose(); }
        else if(strcmp(command_buffer, "rn pt") == 0) { currentCommand = "point"; runPointPose(); }
        else if(strcmp(command_buffer, "rn pu") == 0) { currentCommand = "pushup"; runPushupPose(); }
        else if(strcmp(command_buffer, "rn bw") == 0) { currentCommand = "bow"; runBowPose(); }
        else if(strcmp(command_buffer, "rn ct") == 0) { currentCommand = "cute"; runCutePose(); }
        else if(strcmp(command_buffer, "rn fk") == 0) { currentCommand = "freaky"; runFreakyPose(); }
        else if(strcmp(command_buffer, "rn wm") == 0) { currentCommand = "worm"; runWormPose(); }
        else if(strcmp(command_buffer, "rn sk") == 0) { currentCommand = "shake"; runShakePose(); }
        else if(strcmp(command_buffer, "rn sg") == 0) { currentCommand = "shrug"; runShrugPose(); }
        else if(strcmp(command_buffer, "rn dd") == 0) { currentCommand = "dead"; runDeadPose(); }
        else if(strcmp(command_buffer, "rn cb") == 0) { currentCommand = "crab"; runCrabPose(); }
        else if (strcmp(command_buffer, "subtrim") == 0 || strcmp(command_buffer, "st") == 0) {
          Serial.println("Subtrim values:");
          for (int i = 0; i < 8; i++) {
            Serial.print("Motor "); Serial.print(i); Serial.print(": ");
            if (servoSubtrim[i] >= 0) Serial.print("+");
            Serial.println(servoSubtrim[i]);
          }
        }
        else if (strcmp(command_buffer, "subtrim save") == 0 || strcmp(command_buffer, "st save") == 0) {
          Serial.println("Copy and paste this into your code:");
          Serial.print("int8_t servoSubtrim[8] = {");
          for (int i = 0; i < 8; i++) {
            Serial.print(servoSubtrim[i]);
            if (i < 7) Serial.print(", ");
          }
          Serial.println("};");
        }
        else if (strncmp(command_buffer, "subtrim reset", 13) == 0 || strncmp(command_buffer, "st reset", 8) == 0) {
          for (int i = 0; i < 8; i++) servoSubtrim[i] = 0;
          Serial.println("All subtrim values reset to 0");
        }
        else if (strncmp(command_buffer, "subtrim ", 8) == 0 || strncmp(command_buffer, "st ", 3) == 0) {
          const char* params = (command_buffer[1] == 't') ? command_buffer + 3 : command_buffer + 8;
          int trimMotor, trimValue;
          if (sscanf(params, "%d %d", &trimMotor, &trimValue) == 2) {
            if (trimMotor >= 0 && trimMotor < 8) {
              if (trimValue >= -90 && trimValue <= 90) {
                servoSubtrim[trimMotor] = trimValue;
                Serial.print("Motor "); Serial.print(trimMotor); Serial.print(" subtrim set to ");
                if (trimValue >= 0) Serial.print("+");
                Serial.println(trimValue);
              } else {
                Serial.println("Subtrim value must be between -90 and +90");
              }
            } else {
              Serial.println("Invalid motor number (0-7)");
            }
          }
        }
        else if (strncmp(command_buffer, "all ", 4) == 0) {
             if (sscanf(command_buffer + 4, "%d", &angle) == 1) {
                 for (int i = 0; i < 8; i++) setServoAngle(i, angle);
                 Serial.print("All servos set to "); Serial.println(angle);
             }
        }
        else if (sscanf(command_buffer, "%d %d", &motorNum, &angle) == 2) {
             if (motorNum >= 0 && motorNum < 8) {
                 setServoAngle(motorNum, angle);
                 Serial.print("Servo "); Serial.print(motorNum); Serial.print(" set to "); Serial.println(angle);
             } else {
                 Serial.println("Invalid motor number (0-7)");
             }
        }
        buffer_pos = 0;
      }
    } else if (buffer_pos < sizeof(command_buffer) - 1) {
      command_buffer[buffer_pos++] = c;
    }
  }
}

// Function to update the robot's face
void updateFaceBitmap(const unsigned char* bitmap) {
  display.clearDisplay();
  display.drawBitmap(0, 0, bitmap, 128, 64, SSD1306_WHITE);
  display.display();
}

uint8_t countFrames(const unsigned char* const* frames, uint8_t maxFrames) {
  if (frames == nullptr || frames[0] == nullptr) return 0;
  uint8_t count = 0;
  for (uint8_t i = 0; i < maxFrames; i++) {
    if (frames[i] == nullptr) break;
    count++;
  }
  return count;
}

void setFace(const String& faceName) {
  if (faceName == currentFaceName && currentFaceFrames != nullptr) return;

  currentFaceName = faceName;
  currentFaceFrameIndex = 0;
  lastFaceFrameMs = 0;
  faceFrameDirection = 1;
  faceAnimFinished = false;
  currentFaceFps = getFaceFpsForName(faceName);

  currentFaceFrames = face_defualt_frames;
  currentFaceFrameCount = countFrames(face_defualt_frames, MAX_FACE_FRAMES);

  for (size_t i = 0; i < (sizeof(faceEntries) / sizeof(faceEntries[0])); i++) {
    if (faceName.equalsIgnoreCase(faceEntries[i].name)) {
      currentFaceFrames = faceEntries[i].frames;
      currentFaceFrameCount = countFrames(faceEntries[i].frames, faceEntries[i].maxFrames);
      break;
    }
  }

  if (currentFaceFrameCount == 0) {
    currentFaceFrames = face_defualt_frames;
    currentFaceFrameCount = countFrames(face_defualt_frames, MAX_FACE_FRAMES);
    currentFaceName = "default";
    currentFaceFps = getFaceFpsForName(currentFaceName);
  }

  if (currentFaceFrameCount > 0 && currentFaceFrames[0] != nullptr) {
    updateFaceBitmap(currentFaceFrames[0]);
  }
}

void setFaceMode(FaceAnimMode mode) {
  currentFaceMode = mode;
  faceFrameDirection = 1;
  faceAnimFinished = false;
}

void setFaceWithMode(const String& faceName, FaceAnimMode mode) {
  setFaceMode(mode);
  setFace(faceName);
}

int getFaceFpsForName(const String& faceName) {
  for (size_t i = 0; i < (sizeof(faceFpsEntries) / sizeof(faceFpsEntries[0])); i++) {
    if (faceName.equalsIgnoreCase(faceFpsEntries[i].name)) {
      return faceFpsEntries[i].fps;
    }
  }
  return faceFps;
}
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

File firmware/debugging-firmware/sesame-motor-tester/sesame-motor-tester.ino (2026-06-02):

#include <Arduino.h>
#include <ESP32Servo.h>

// ======================================================================
// --- CONFIGURATION ---
// ======================================================================

Servo servos[8];

// Motor Pin Mapping
// Index: 0  1  2  3  4   5   6   7
const int servoPins[8] = {8, 10, 6, 4, 14, 13, 2, 1};
// Distro board pins: (uncomment if needed)
// const int servoPins[8] = {15, 2, 23, 19, 4, 16, 17, 18};



// Pulse width settings
const int MIN_PULSE = 732;
const int MAX_PULSE = 2929;

// ======================================================================
// --- SETUP ---
// ======================================================================

void setup() {
  Serial.begin(115200);
  while (!Serial);

  Serial.println("-----------------------------------");
  Serial.println("   Sesame Motor Tester Interface   ");
  Serial.println("-----------------------------------");
  Serial.println("Commands:");
  Serial.println("1. id,angle   -> e.g. '0,90'");
  Serial.println("2. all,angle  -> e.g. 'all,90'");
  Serial.println("3. stop       -> Detaches/Powers down motors");
  Serial.println("-----------------------------------");
  Serial.println("Status: Motors are currently OFF (Limp).");

  // Allocate timers for ESP32Servo
  ESP32PWM::allocateTimer(0);
  ESP32PWM::allocateTimer(1);
  ESP32PWM::allocateTimer(2);
  ESP32PWM::allocateTimer(3);

  // We do NOT attach motors here. They stay limp until a command is sent.
}

// ======================================================================
// --- MAIN LOOP ---
// ======================================================================

void loop() {
  if (Serial.available() > 0) {
    String input = Serial.readStringUntil('\n');
    input.trim(); // Remove whitespace/newlines

    if (input.length() == 0) return;

    // --- Check for STOP command ---
    if (input.equalsIgnoreCase("stop")) {
      stopMotors();
      return;
    }

    // --- Parse "key,value" format ---
    int commaIndex = input.indexOf(',');
    
    if (commaIndex != -1) {
      String cmd = input.substring(0, commaIndex);
      String valStr = input.substring(commaIndex + 1);
      int angle = valStr.toInt();

      // Check Angle Limits
      if (angle < 0) angle = 0;
      if (angle > 180) angle = 180;

      // Check if command is "all" or a motor ID
      if (cmd.equalsIgnoreCase("all")) {
        moveAll(angle);
      } else {
        // Assume it's a number
        int motorId = cmd.toInt();
        // Basic check to ensure "0" wasn't actually text garbage
        if (motorId == 0 && cmd.charAt(0) != '0') {
           Serial.println("Error: Invalid Motor ID");
        } else {
           moveMotor(motorId, angle);
        }
      }
      
    } else {
      Serial.println("Error: Invalid format. Use 'id,angle', 'all,angle', or 'stop'.");
    }
  }
}

// ======================================================================
// --- HELPER FUNCTIONS ---
// ======================================================================

void moveMotor(int id, int angle) {
  if (id < 0 || id > 7) {
    Serial.println("Error: Motor ID must be 0-7");
    return;
  }

  // If servo isn't attached yet (powered off), attach it now
  if (!servos[id].attached()) {
    servos[id].setPeriodHertz(50);
    servos[id].attach(servoPins[id], MIN_PULSE, MAX_PULSE);
  }

  servos[id].write(angle);
  
  Serial.print("OK: Motor ");
  Serial.print(id);
  Serial.print(" -> ");
  Serial.println(angle);
}

void moveAll(int angle) {
  Serial.print("Moving ALL to ");
  Serial.println(angle);
  for (int i = 0; i < 8; i++) {
    moveMotor(i, angle);
  }
}

void stopMotors() {
  Serial.println("Stopping (Detaching) all motors...");
  for (int i = 0; i < 8; i++) {
    if (servos[i].attached()) {
      servos[i].detach();
    }
  }
  Serial.println("Motors are now OFF.");
}

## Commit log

2026-06-02 Add new file a in hardware/pcb_v2 directory
2026-06-02 Crear carpeta pcb_v2 y agregar archivos
    [PCB_sesame.kicad_pcb, PCB_sesame.kicad_sch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]
2026-06-02 Mover pcb_v2 dentro de hardware
    [PCB_sesame.kicad_pcb, PCB_sesame.kicad_sch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]
